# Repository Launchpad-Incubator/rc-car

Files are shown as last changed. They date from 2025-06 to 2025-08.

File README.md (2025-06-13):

# RC Car Control System (Raspberry Pi Pico W + Python)

This project provides a complete system for controlling RC cars over Wi-Fi using Raspberry Pi Pico W microcontrollers. Each car is configured individually, connects to a shared wireless network, and is controlled from a host computer using real-time keyboard input.

## 🚗 Project Components

### 🧠 On the RC Car (Pico W):
- Reads PWM config from `config.json`
- Connects to Wi-Fi using `networkinfo.json`
- Listens for HTTP control commands (`/api?cmd=...&turn=...`)
- Drives an ESC (motor) and servo (steering) using MicroPython

### 💻 On the Control Host (Mac or PC):
- `control_rc_car.py` script
- Sends commands via HTTP using WASD keyboard input
- Uses `.local` mDNS hostnames for multi-car control

---

## 📦 File Structure

```
rc-car-control/
├── main.py               # Pico W control script
├── control_rc_car.py     # Mac/PC keyboard controller
├── config.json           # Pico hardware & hostname config
├── networkinfo.json      # Pico Wi-Fi credentials
├── requirements.txt      # Python dependencies for host control
└── README.md             # You’re here
```

---

## 🛠️ Setup Instructions

### 🔧 1. Flashing the Pico W

1. Flash MicroPython to the Pico W (https://micropython.org/download/rp2-pico-w/)
2. Use [Thonny](https://thonny.org/) to connect to the Pico
3. Upload `main.py`, `config.json`, and `networkinfo.json`
4. Save `main.py` directly on the Pico (not your computer)

### 📡 2. Configuring Wi-Fi and Hostname

Example `config.json` (on the Pico):
```json
{
  "hostname": "rc1",
  "esc_pin": 16,
  "servo_pin": 17
}
```

Example `networkinfo.json` (on the Pico and the computer):
```json
{
  "SSID": "YourWiFiNetwork",
  "PASSWORD": "YourWiFiPassword"
}
```

⌨️ 3. Running the Host Control Script

Install dependencies:
```bash
pip install -r requirements.txt
```

Run the control script:
```bash
python control_rc_car.py
```

You can now control the car using:

    W = Forward
    S = Stop
    A/D = Left/Right steering

---

🚙 Multi-Car Setup

You can run multiple RC cars simultaneously on the same network by:
   1.  Giving each car a unique hostname in its config.json (e.g., rc1, rc2, rc3, …)
   2.  Updating your control script to point to different cars via hostname (rc2.local, etc.)

---

🧪 Testing

    •   Press W while connected to verify motor spin
    •	Watch onboard LED:
    •	Fast blink while connecting to Wi-Fi
    •	Solid once connected
    •	Use ping `rc1.local` to test mDNS resolution

---

📋 Requirements

    •   Raspberry Pi Pico W
    •   GoolRC ESC + Brushless Motor
    •	Servo motor (3-wire)
    •	URGENEX 7.4V 2000mAh battery
    •	Python 3.9+ on control host

---

🤝 Contributing

    1.	Fork the repo
    2.	Create a feature branch (git checkout -b feature/my-feature)
    3.	Commit changes and push
    4.	Open a pull request

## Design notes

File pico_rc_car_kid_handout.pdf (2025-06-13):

## RC Car Code on the Pico W - Explained for Kids

What This Code Does

This code runs on the tiny computer (called a Pico W) that lives inside your RC car. It listens for messages from your laptop over Wi-Fi and makes the car go forward, stop, or turn!

How It Connects to Wi-Fi

At the start of the program, the Pico reads two files:
- config.json: which pins control the motor and the steering
- networkinfo.json: the name and password for your Wi-Fi

It then connects to Wi-Fi. While it's trying to connect, it blinks its little LED light. Once it connects, the light stays on so you know it's ready.

What Is a Class?

In Python, a class is like a blueprint. This code defines a class called RCCar. That blueprint tells the Pico how to control the car: how to drive forward, turn, or stop. We make one real car using that blueprint by writing: car = RCCar(esc, servo).

What is PWM?

PWM stands for Pulse Width Modulation. It means turning power on and off very quickly in pulses. The motor and the steering servo need different length pulses to know what to do. The car sends these using the PWMOutput class.

What is a Socket?

A socket is like a phone line. The Pico sets up a socket and listens on it for incoming messages. When your computer sends a message, the Pico 'picks up the phone' and checks what you said. If you said 'forward', the car moves forward!

How Commands Work

The Pico listens for messages like this:

## RC Car Code on the Pico W - Explained for Kids

GET /api?cmd=forward&turn=left
It looks at the 'cmd' and 'turn' parts and figures out what to do.
- cmd=forward -> drive forward
- turn=left -> steer left
This is called an HTTP GET request. It's how computers ask other computers for something on the web.

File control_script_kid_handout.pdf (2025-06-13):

## RC Car Keyboard Controller - Explained for Kids

What This Program Does

This Python program runs on your computer. It watches your keyboard and sends drive commands to your RC car over Wi-Fi!

How It Knows What Car to Talk To

The program reads config.json to learn the car's hostname, like 'rc1'. It turns that into something like 'http://rc1.local' to send messages to the car.

What is an HTTP Request?

HTTP is a way for computers to ask each other for things, like a website. When you press the 'W' key, your computer sends a message like:
GET /api?cmd=forward&turn=center
The car sees this and goes forward.

How Key Presses Become Car Moves

The program uses a Python package called 'keyboard'. It checks over and over to see which keys are pressed:
- W = go forward
- S = stop
- A = turn left
- D = turn right
Then it sends the right command to the car. If you let go, it tells the car to stop or steer straight.

How Networking Works (Simply)

Think of your home Wi-Fi like a neighborhood. Each device (your computer, the car) has a house number (IP address).
When your computer wants to talk to the car, it sends a letter to that number.
In our case, the letter says something like 'please drive forward'.

## RC Car Keyboard Controller - Explained for Kids

How It Keeps Talking

The program remembers the last command it sent. If nothing has changed, it doesn't send the same command again. This helps it run smoothly without spamming the car.

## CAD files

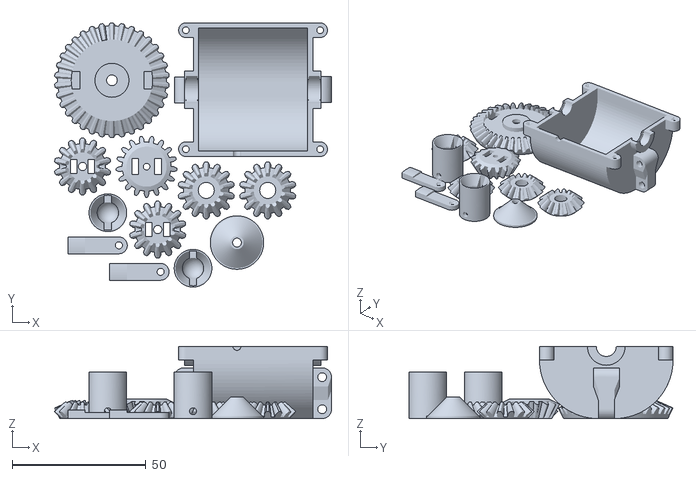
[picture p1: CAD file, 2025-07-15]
RC Car v3.5/Gearbox Batch v1.1.stl
103.6 x 98.8 x 27.0

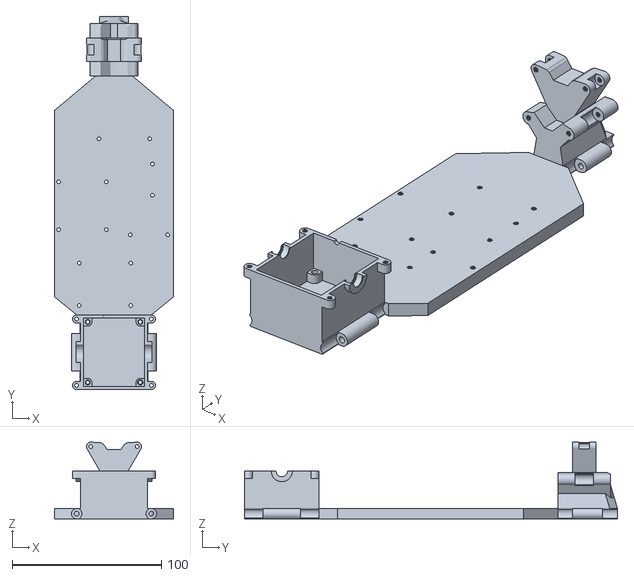
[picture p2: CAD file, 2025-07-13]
RC Car v3.5/PLA/6 Walls, 30% Infill, Tree Support, Crit Regions/RC+car_ parts - Base.stl
80.0 x 250.0 x 51.5

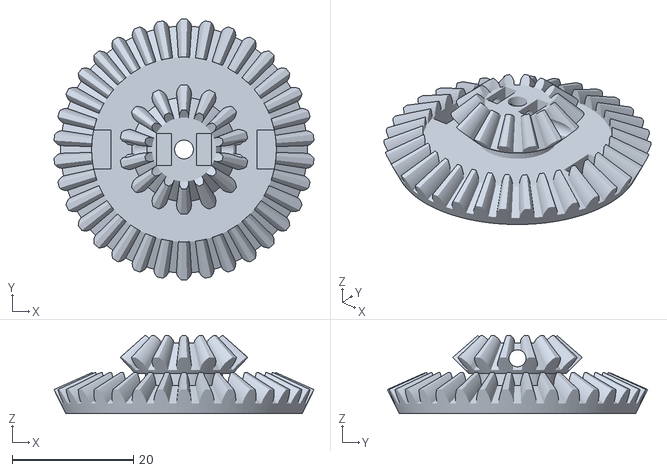
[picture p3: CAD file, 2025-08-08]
RC Car v3.5/PLA/Default/Large+gear_v2.stl
42.9 x 43.0 x 12.9

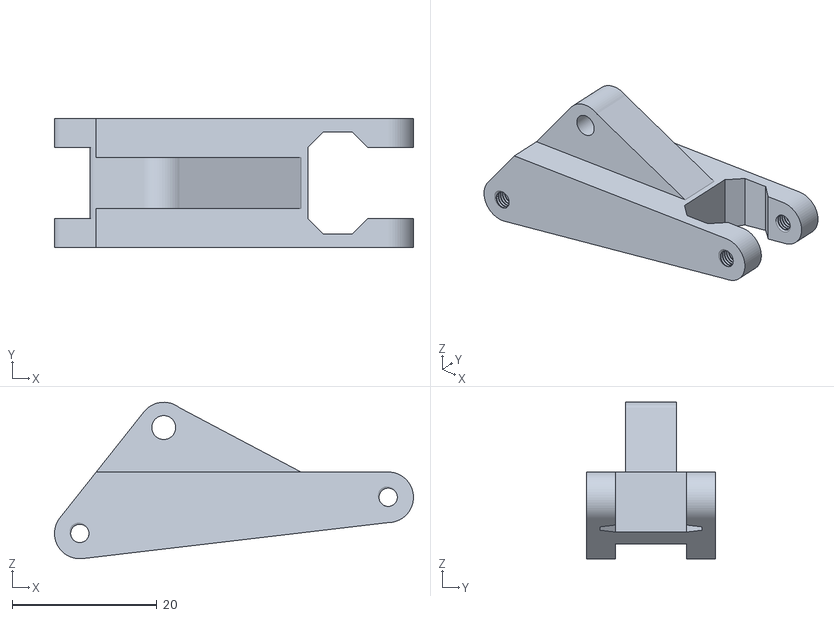
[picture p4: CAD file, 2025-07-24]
RC Car v3.5/PLA/Tree Support, Crit Regions/Back Top Arm v2.stl
49.6 x 17.8 x 21.6

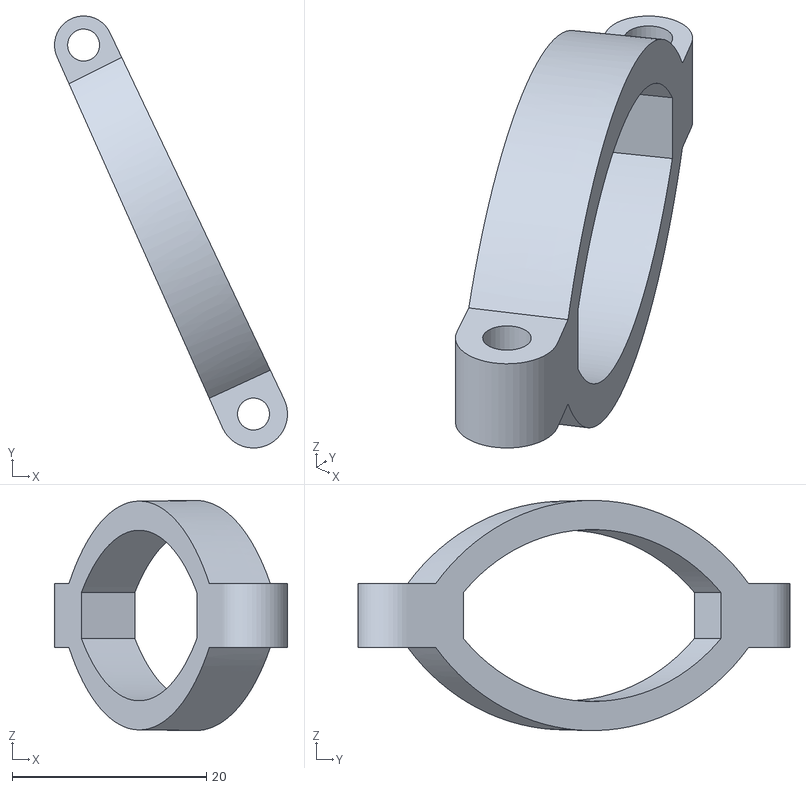
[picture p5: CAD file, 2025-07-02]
RC Car v3.5/TPU/Default/Suspension.stl
24.0 x 44.5 x 23.7

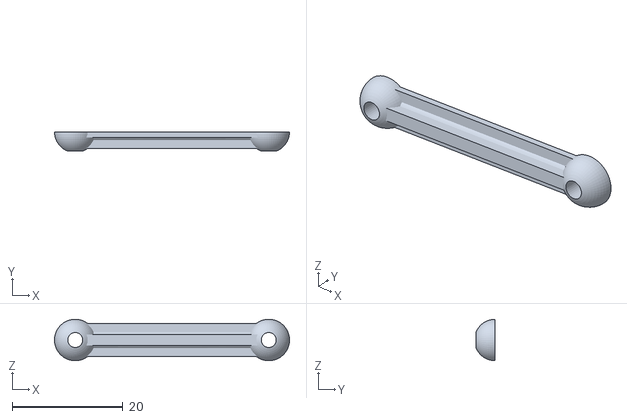
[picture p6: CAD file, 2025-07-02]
RC Car v3.5/PLA/6 Walls, 30% Infill, Tree Support, Crit Regions/Driver+arm.stl
42.5 x 3.50 x 7.49

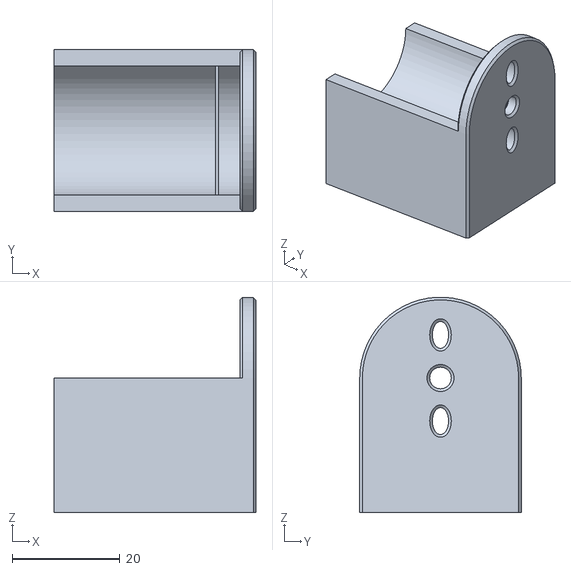
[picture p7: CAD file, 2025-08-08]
RC Car v3.5/PLA/Default/Motor Mount v1.1.stl
37.5 x 30.0 x 40.0

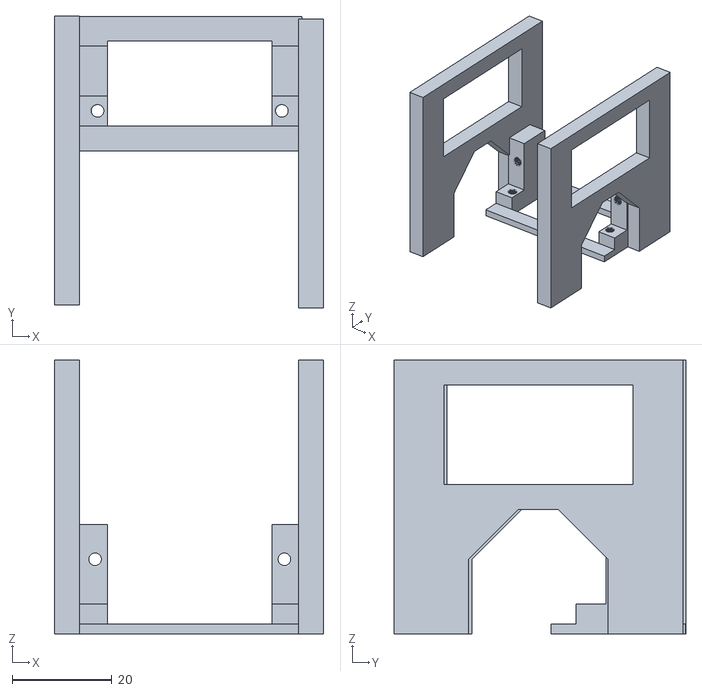
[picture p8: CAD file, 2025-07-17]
RC Car v3.5/PLA/Tree Support, Crit Regions/Servo_Battery_Mount_v2.2.stl
54.0 x 58.6 x 55.0

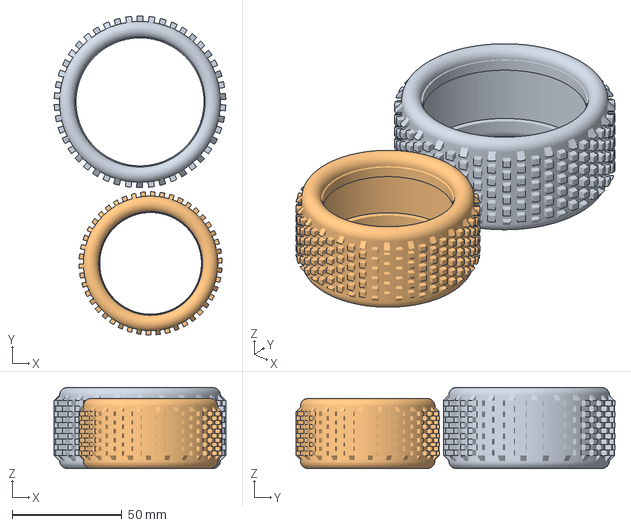
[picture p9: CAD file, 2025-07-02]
RC Car v3.5/TPU/Default/Back+Suspension.3mf
78.4 x 145.6 x 37.0 mm
Rear Tyre v2.stl
Front Tire v2.stl

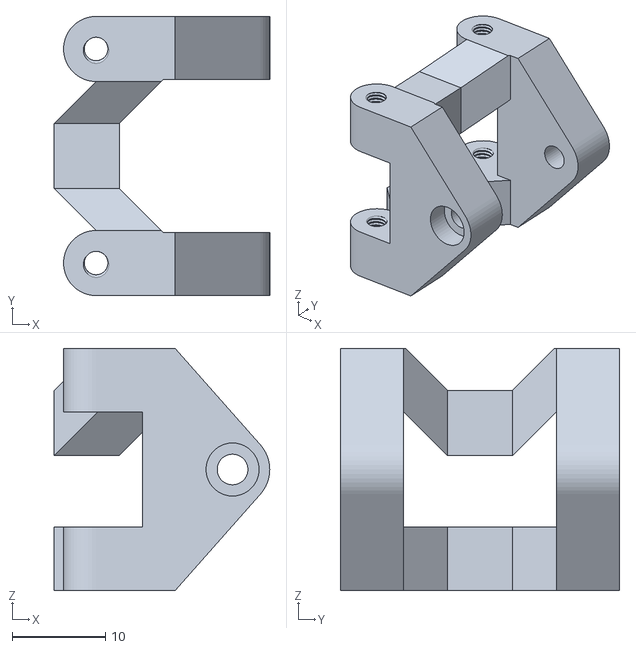
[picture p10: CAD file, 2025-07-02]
RC Car v3.5/PLA/6 Walls, 30% Infill, Tree Support, Crit Regions/Steering+Bracket.stl
23.2 x 30.0 x 26.0

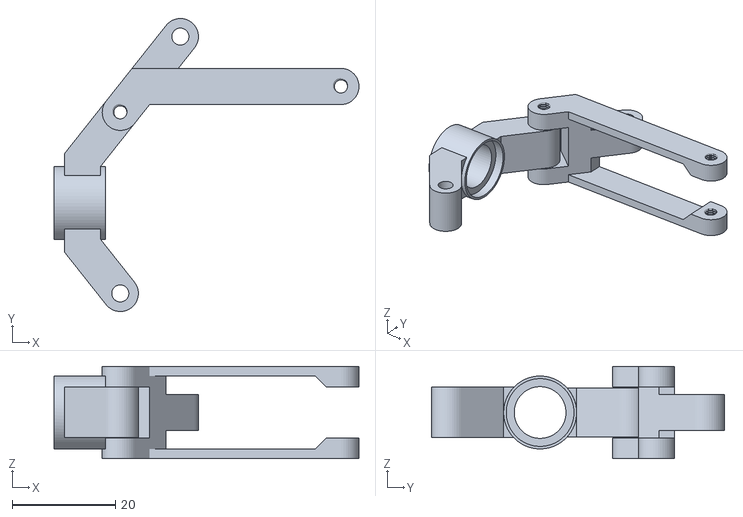
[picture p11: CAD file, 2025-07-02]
RC Car v3.5/PLA/Tree Support, Crit Regions/Back wheel holder.stl
59.0 x 56.6 x 17.8

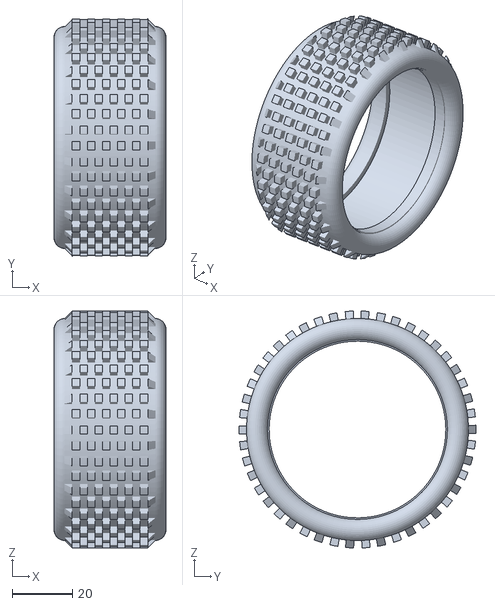
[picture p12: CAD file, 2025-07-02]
RC Car v3.5/TPU/Default/Rear Tyre v2.stl
37.0 x 78.4 x 78.4

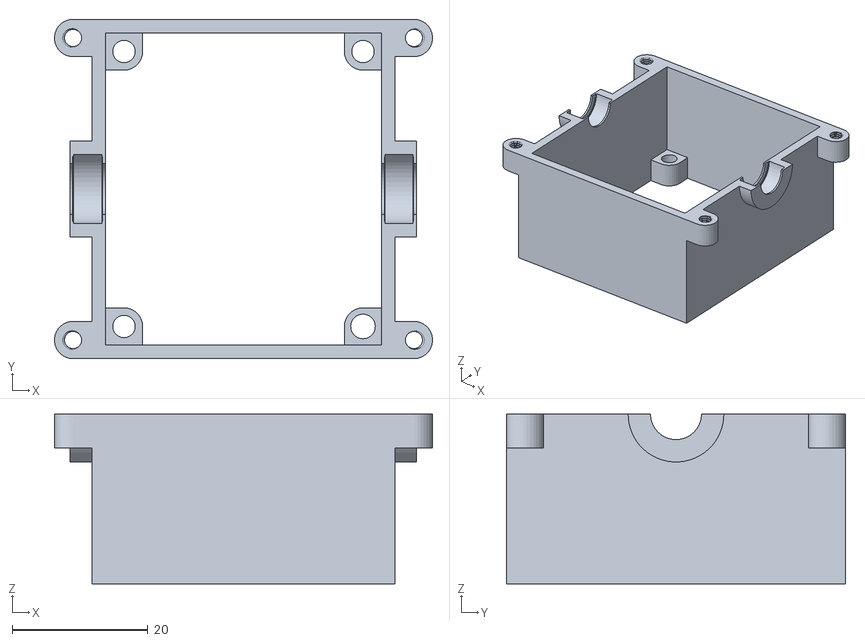
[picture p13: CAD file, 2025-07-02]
RC Car v3.5/PLA/Default/Bottom+Gear+box+UPD.stl
55.7 x 50.0 x 25.0

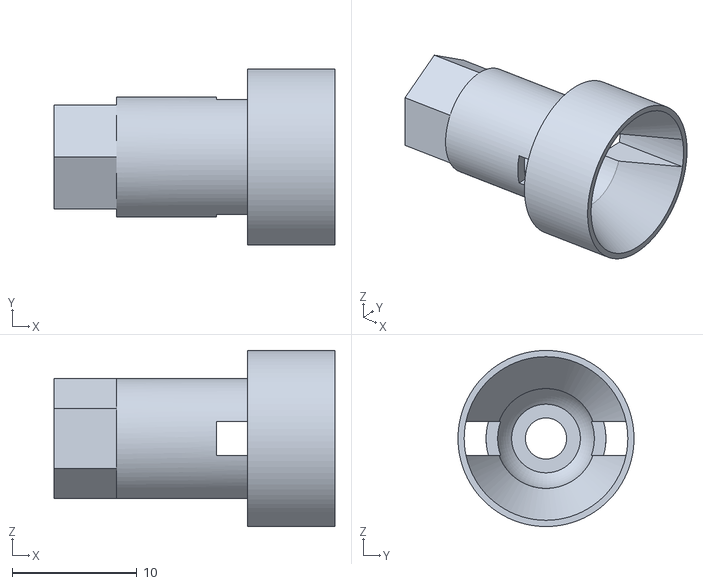
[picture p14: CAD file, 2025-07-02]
RC Car v3.5/PLA/Tree Support, Crit Regions/Back wheel connector.stl
22.5 x 14.1 x 14.1

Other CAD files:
RC Car v3.5/TPU/Default/Front Tire v2.stl
RC Car v3.5/PLA/Default/Inner+gear.stl
RC Car v3.5/PLA/Tree Support, Crit Regions/Back Hub.3mf
RC Car v3.5/PLA/Default/Inner+Driver+Gear.stl
RC Car v3.5/PLA/Default/Back+gearbox+connector.stl
RC Car v3.5/PLA/Default/Driver Gear v3.5.stl
RC Car v3.5/PLA/Default/Fat Washer v1.0.3mf
RC Car v3.5/PLA/Default/Front+arm+top.stl
RC Car v3.5/PLA/Default/Front+arm.stl
RC Car v3.5/PLA/Default/Gear+Arm_v2.stl
RC Car v3.5/PLA/Default/Large+gear.stl
RC Car v3.5/PLA/Default/Rear Wishbone.stl
RC Car v3.5/PLA/Default/Steering+arm.stl
RC Car v3.5/PLA/Default/center+arm.stl
RC Car v3.5/PLA/Tree Support, Crit Regions/Front Hub.stl
RC Car v3.5/PLA/Tree Support, Crit Regions/Top+gear+box.stl
RC Car v3.5/PLA/Tree Support, Crit Regions/Wheel+Bracket.stl
RC Car v3.5/TPU/Default/Back+Suspension.stl

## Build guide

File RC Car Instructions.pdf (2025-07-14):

Supplies

Electronic components:
Motor
Speed controller
Battery
Receiver and transmitter
Servo

Screws:
All the screws are M3 screws unless specified otherwise 4x 8mm
19x 10mm
12x 16mm
8x 22mm
2x 25mm
4x 30mm
4x 40mm
4x nylon locking nut
8x M2.5 5mm set screw
8x M2.5 nut
Other:
3mm Steel Rod (At least 50mm, 25mm each)
9x 623ZZ bearings

Original Instructables File: https://www.instructables.com/3D-Printed-RC-Car/

Step 1: Print Chassis

Send the revised chassis to print.

Step 2: Servo

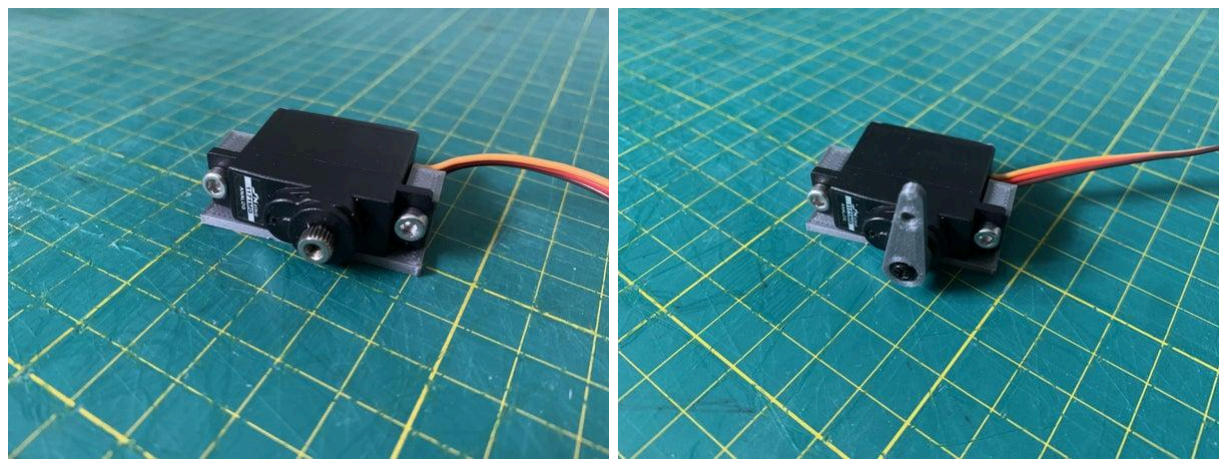
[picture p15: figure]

SKIP IF NOT ATTENDING WEEK 2
Attach the servo to the servo mount using two 10mm screws.
Attach the servo arm to the servo with the really small screw. These parts come with the servo motor.

servo mount.stl (https://content.instructables.com/FE1/2BOT/LJWVJSE4/FE12BOTLJWVJSE4.stl)

servo arm.stl (https://content.instructables.com/F8K/LF18/LJWVJSE5/F8KLF18LJWVJSE5.stl)

Step 3: Steering Arms

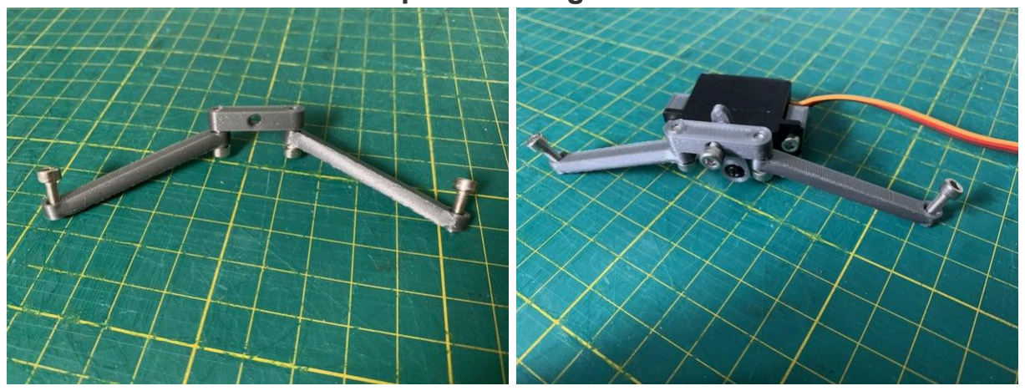
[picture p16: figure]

- Screw the Steering Arms to the Center Arm using 10mm M3 screws. The screws come up from the bottom and the arms “point” downward.
- Make sure that the arms can rotate around the screws freely on both ends of both steering arms. If they do not, loosen the screws slightly. If that doesn’t work, file out the inside of the Steering Arm (not the Center Arm).
- Attach the centre part to the servo arm using the pointy screw that came with the Servo.

Steering arm.stl (https://content.instructables.com/FER/DNH0/LJWVJSEF/FERDNH0LJWVJSEF.stl)

center arm.stl (https://content.instructables.com/FQ3/DND9/LJWVJSEH/FQ3DND9LJWVJSEH.stl)

Step 4: Front Wheels

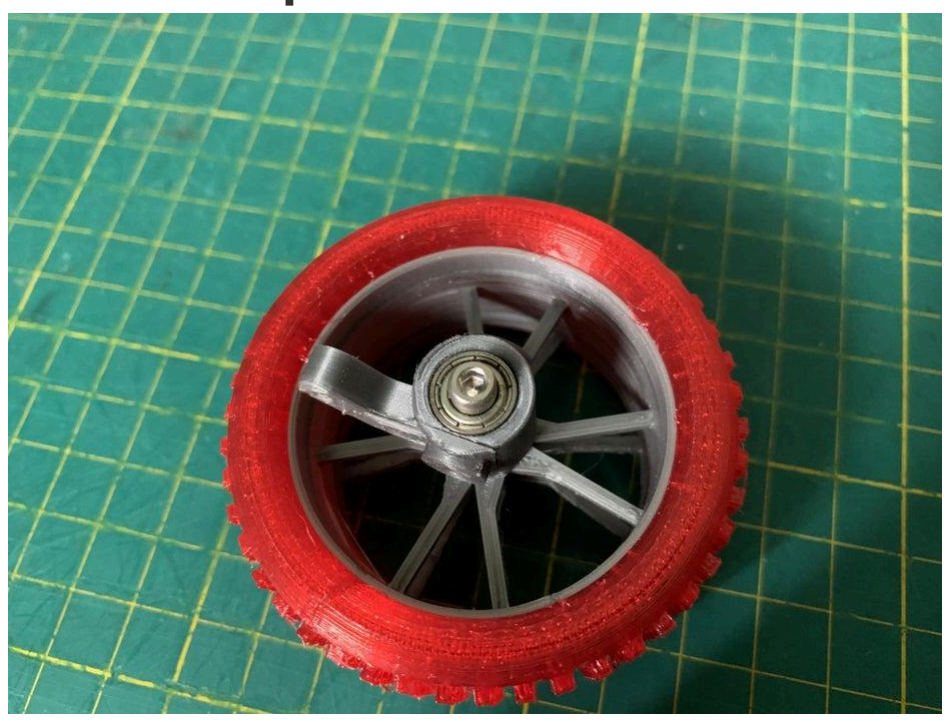
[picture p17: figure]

- Press the bearings into the holes (two on each Wheel Bracket). You will probably need to use a vise.
- Put a 30mm screw through the center of the Wheel Bracket, then a washer, then the Rim.
- Screw on a “Nyloc” nut to stop the Rim from coming off.

Wheel Bracket.stl (https://content.instructables.com/FQH/8DWZ/LJWVJSEU/FQH8DWZLJWVJSEU.stl)

Rim.stl (https://content.instructables.com/F7K/WS2S/LJWVJSEV/F7KWS2SLJWVJSEV.stl)

Tyre.stl (https://content.instructables.com/FEG/O1PX/LJWVJSEW/FEGO1PXLJWVJSEW.stl)

Step 5: Front Arm

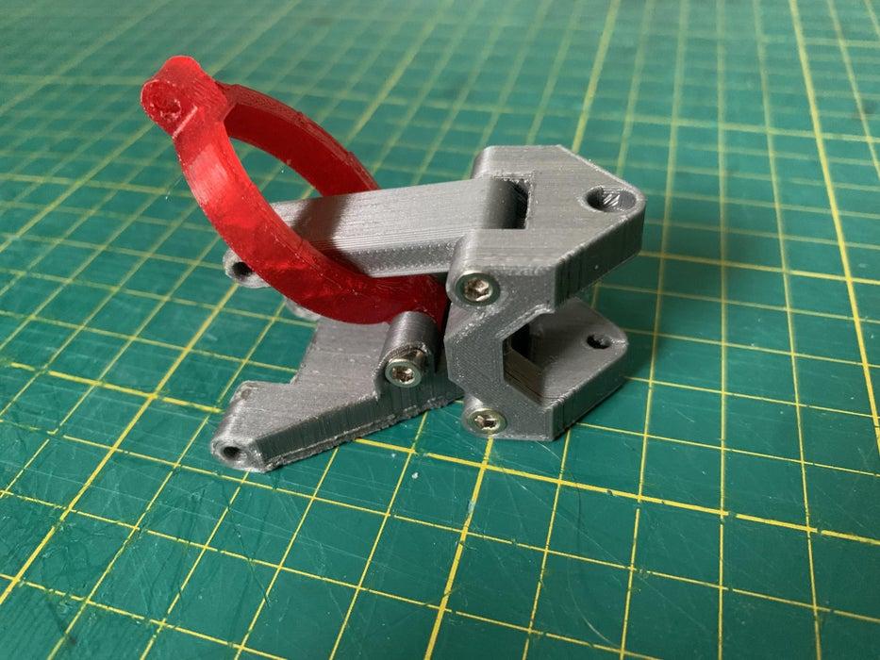
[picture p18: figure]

- Screw the wishbone (front arm) to the chassis using a 40mm screw.
- Screw the wishbone to the steering bracket using 22mm screws.
- Screw the Front Upper Arm to the steering bracket using 22mm screws.
- Screw the suspension piece to the steering bracket (with the thickest piece towards the wheel) using 18mm screws.
- Make sure that all of these pieces can rotate and move freely.
- PRINT 2 (MIRRORED)

Front arm.stl (https://content.instructables.com/F0T/OI95/LJWVJSFE/F0TOI95LJWVJSFE.stl)

Front arm top.stl (https://content.instructables.com/FYB/U8QN/LJWVJSFF/FYBU8QNLJWVJSFF.stl)

Steering Bracket.stl (https://content.instructables.com/FX6/MYU9/LJWVJSFG/FX6MYU9LJWVJSFG.stl)

Suspension.stl (https://content.instructables.com/FYJ/JQRL/LJWVJSFH/FYJJQRLLJWVJSFH.stl)

Step 6: Attaching the Wheel

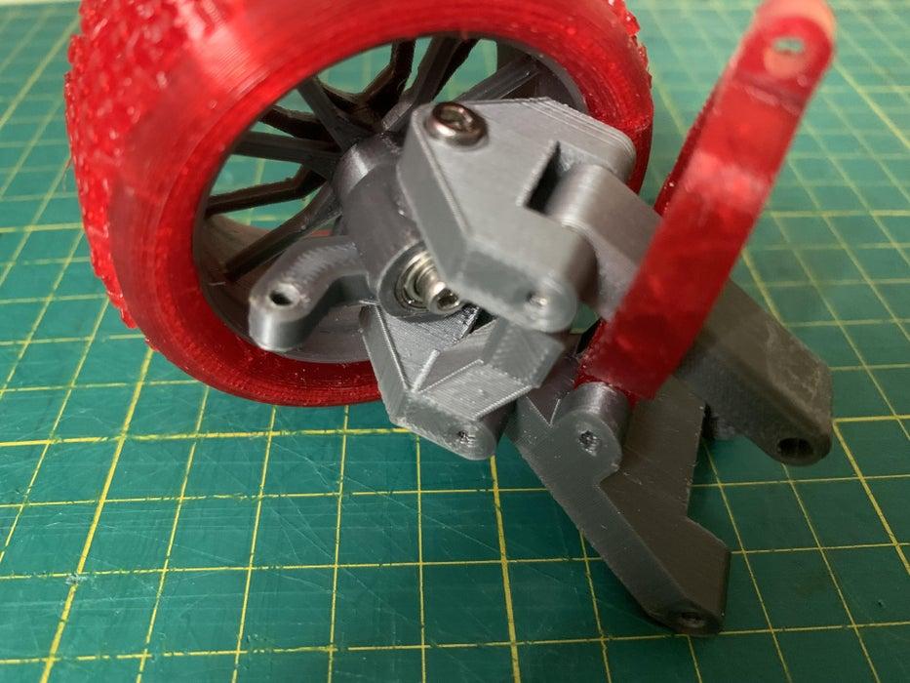
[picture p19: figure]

- Screw Steering Bracket to the Wheel Bracket with 8mm screws for the top and bottom.
- Check that the wheel rotates freely, left to right.
Step 6: Finishing the Front Arms

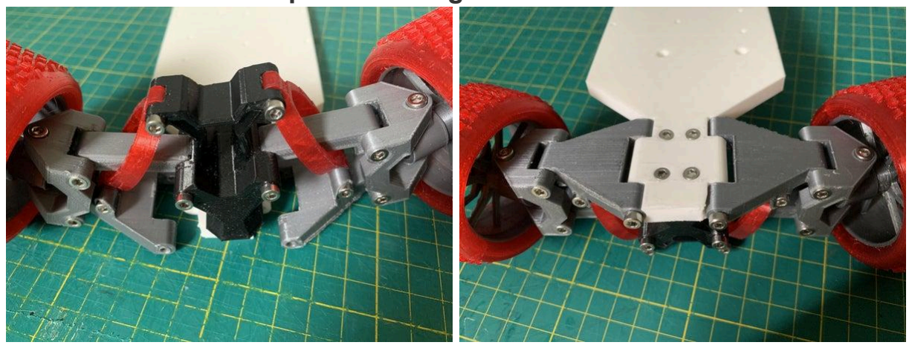
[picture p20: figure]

- Screw the suspension to the Front Arm Bracket (this is now part of the chassis print) using 16mm screws
- Screw on the top wishbones using 30mm screws.

Step 8: Finalising the Steering

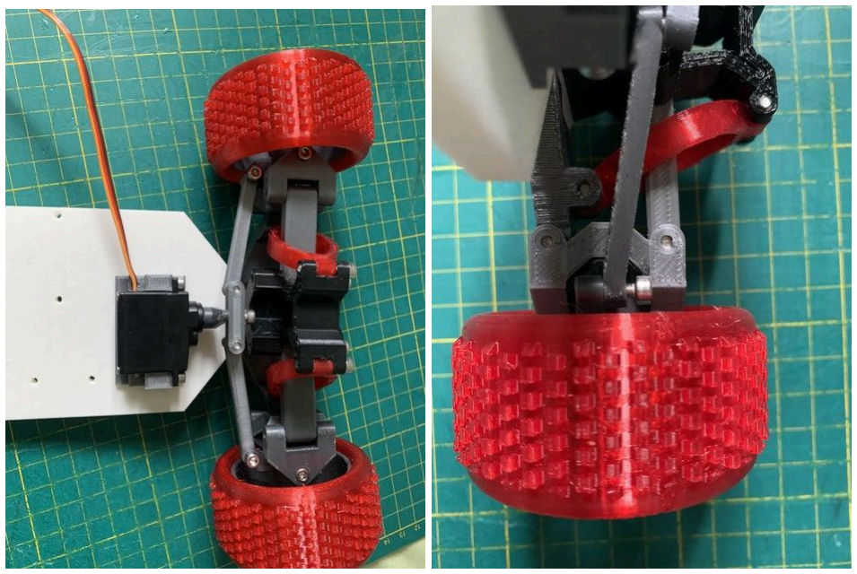
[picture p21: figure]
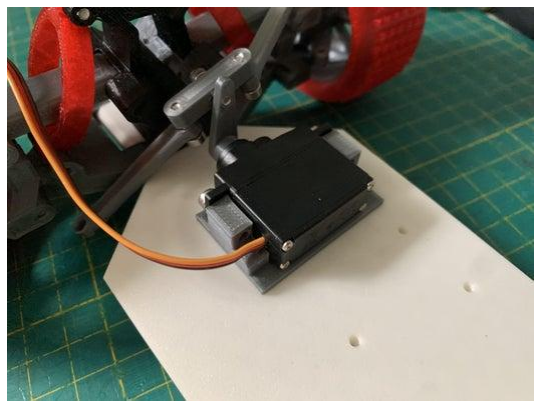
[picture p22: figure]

- Screw the servo to the base using 10mm screws.
- Screw the steering arms to the Wheel Bracket using 10mm screws making sure that there is enough room for the arm to move up and down a little bit.

Step 9: Driver Arm

Print FOUR Driver Arms.

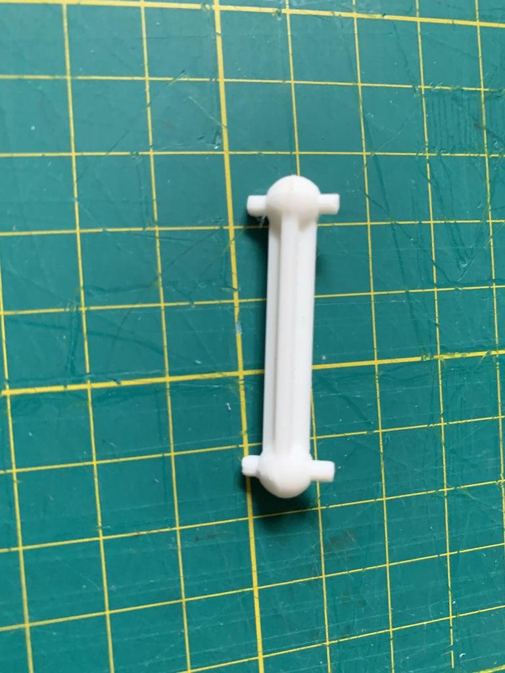
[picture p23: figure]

With those Driver Arms, make TWO identical drive shafts:

- Cut 12 mm long pieces of a 2.5mm aluminum rod, to make each pin (you need 2 pins for each drive shaft, so 4 pins in total).
- Glue the two halves of the drive shafts together with super glue, and use blue tape to hold the pieces in place while the glue dries.
- Once the glue is dry (about 10 minutes), put a small drop of super glue in the hole, and then push the pins through the holes, so they look like the picture above.

Driver arm.stl (https://content.instructables.com/FNH/9UIH/LJWVJSG1/FNH9UIHLJWVJSG1.stl)

Step 10: Small Gear Assembly

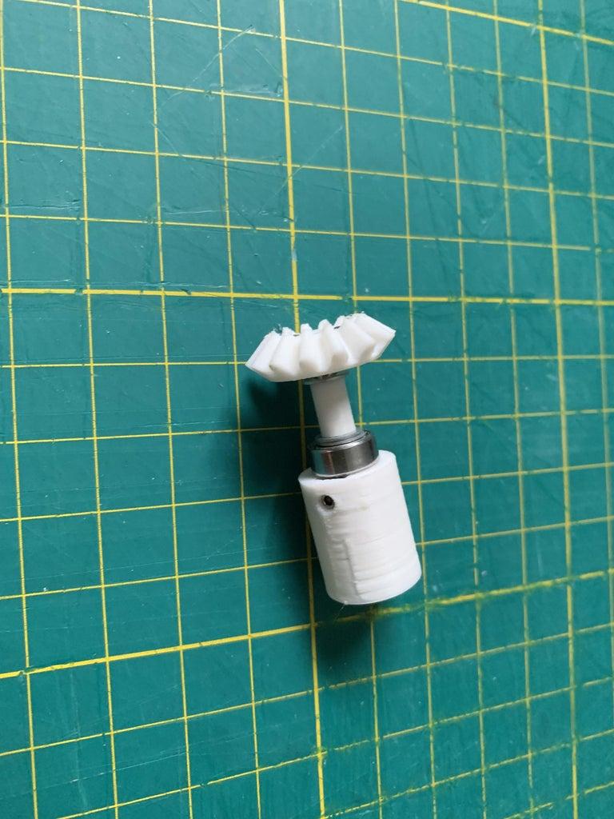
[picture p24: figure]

- Cut a 3mm thick aluminum rod to 23mm (use a hand saw with a “metal” blade). A piece of blue tape at 23mm can act as a guide.
- Put the M2.5 nuts in the slots from the top of the Inner Drive Gear, and screw them in with the M2.5 5mm set screw so the threads just barely catch.
- Insert the gear onto one end of the aluminum rod, and tighten the set screws.
- Put one washer onto the aluminum rod, then the Fat Washer, then two washers, and finally a bearing.
- Check for fit by placing the assembly into the gearbox so that when you put on the gearbox connector, it is not too tight (see the image in Step 10).
- Put the M2.5 nuts in the slots of the gearbox connector, and screw then in with the M2.5 5mm set screws so the threads just barely catch.
- Put the gear box connector onto the aluminum rod, and tighten the set screws.

Inner Driver Gear.stl (https://content.instructables.com/FWM/CVX8/LJWVJSGR/FWMCVX8LJWVJSGR.stl)

Back gearbox connector.stl (https://content.instructables.com/F02/06WU/LJWVJSGT/F0206WULJWVJSGT.stl)

Step 11: Large Gear Assembly

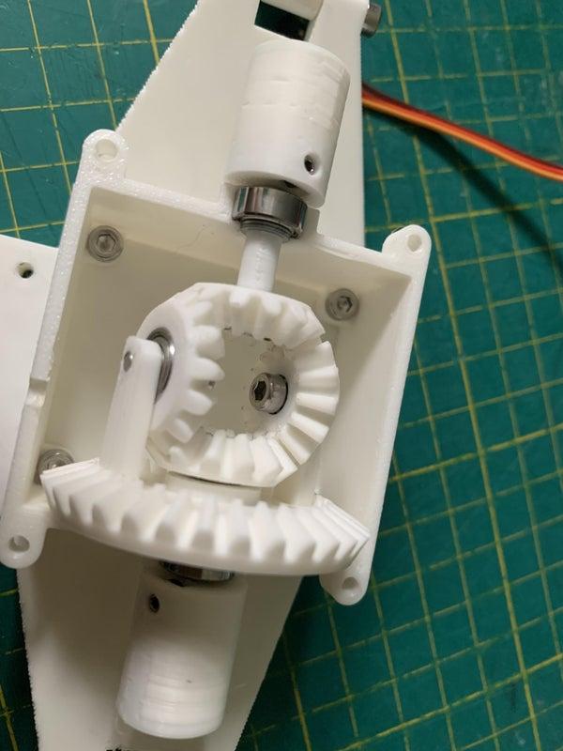
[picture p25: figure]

- Assemble Inner Gear Arm Assemblies
- Put bearings in the Inner Gears (the gears with the hole for the bearing). You may need to use a vise.
- Screw each Inner Gear to a Gear Arm using 8mm screws making sure that they can spin freely.
- Assemble Large Gear Assembly
- Cut a 3mm thick aluminum rod to 45 mm (use a hand saw with a “metal” blade or wire cutters in circles).
- Put in the M2.5 nut in the slots from the top of the Inner Driver Gear, and screw it in with the M2.5 5mm set screw so the threads just barely catch.
- Insert the Inner Drive Gear onto one end of the aluminum rod, and tighten the set screws.
- Press a bearing into the Large Gear, and put it onto the aluminum rod, then another washer
- Assemble the Large Gear Assembly
- Put a drop of super glue into the small rectangular indents on the Large Gear.
- Press the Gear Arms into the Large Gear, making sure that the gears are lined up, and put it aside so that the glue can dry.

Back gearbox connector.stl (https://content.instructables.com/F7Q/WPPE/LJWVJSHJ/F7QWPPELJWVJSHJ.stl)

Small Gear.stl (https://content.instructables.com/FBC/S8TM/LJWVJSHK/FBCS8TMLJWVJSHK.stl)

Gear Arm.stl (https://content.instructables.com/FCL/88L7/LJWVJSHL/FCL88L7LJWVJSHL.stl)

Inner Driver Gear.stl (https://content.instructables.com/F1J/REBV/LJWVJSHM/F1JREBVLJWVJSHM.stl)

Inner gear.stl (https://content.instructables.com/FSI/AYPA/LJWVJSHN/FSIAYPALJWVJSHN.stl)

Large gear.stl (https://content.instructables.com/FPC/1R1D/LJWVJSHO/FPC1R1DLJWVJSHO.stl)

Step 12: Finishing the Gearbox

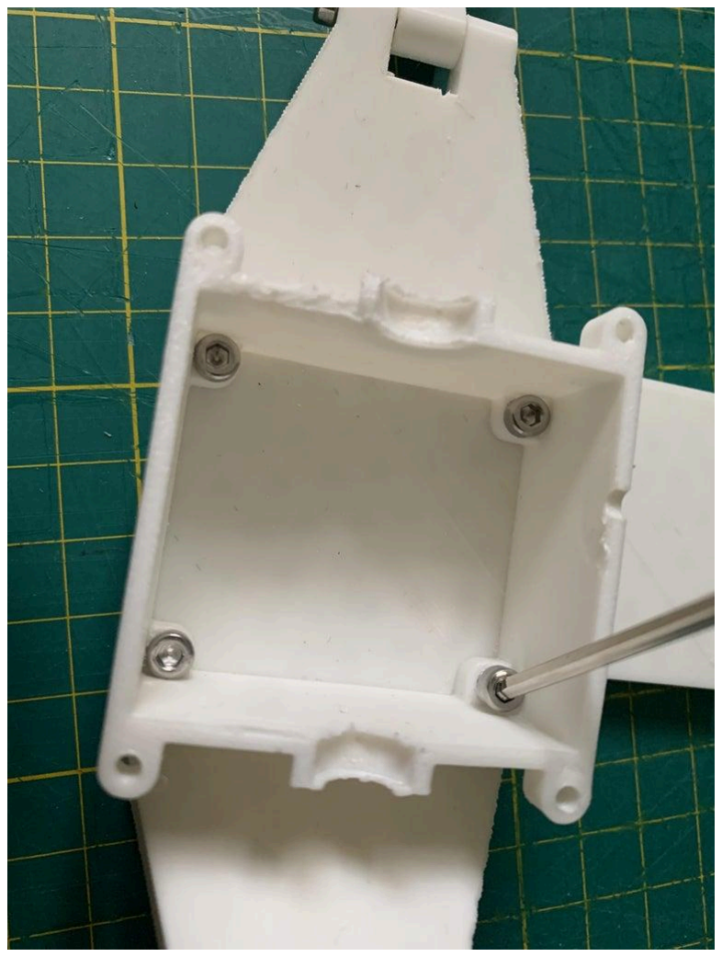
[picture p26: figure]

- Screw the bottom of the gearbox to the Chassis with 10mm screws, and 16mm screws
- Insert all the gears

Bottom Gear box.stl (https://content.instructables.com/F63/7CAI/LJWVJSJD/F637CAILJWVJSJD.stl)

Step 13: Motor

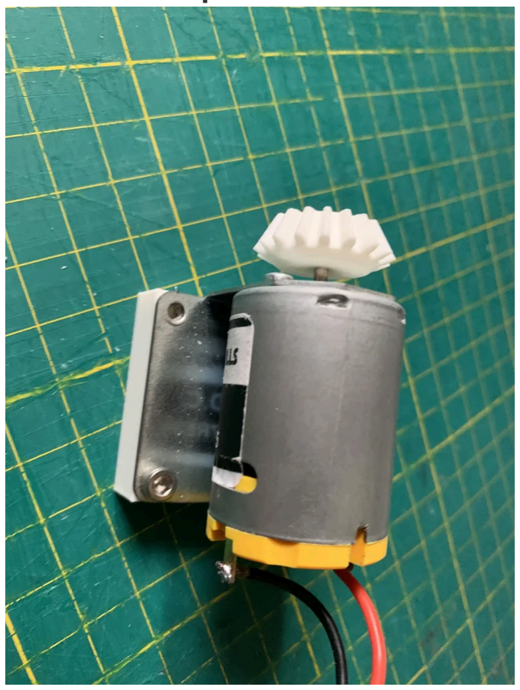
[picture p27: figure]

- Screw the motor onto the Motor Mount (not from the Instructable).
- Screw or glue the motor mount onto the chassis, aligning the drive shaft with the small indent in the gear box. This should be as close to the gearbox as possible.
- Put the M2.5 nuts in the slots from the top of the Motor Gear (not in the Instructable), and screw them in with the M2.5 5mm set screw so the threads just barely catch.
- Insert the gear onto the drive shaft of the motor, and tighten the set screws.

Step 14: Back Arm

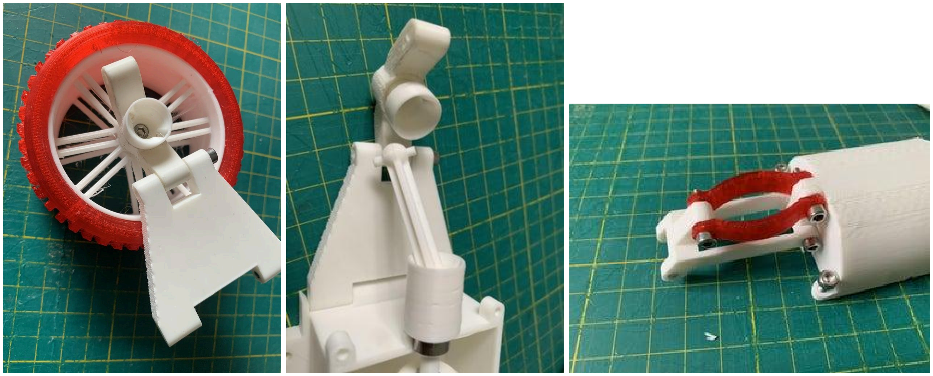
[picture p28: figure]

- Assemble Rear Wheel Assemblies (2 are needed)
- Insert the Back Wheel Connector through the Back Wheel Holder.
- Put an 18mm screw through the Back Wheel Connector.
- Put the Back Wheel Rim onto the screw, and secure them with a NyLock nuts.
- Assemble Upper Suspension Assembly
- Screw the Back Top Arms to the top of the Top Gear using 18mm screws.
- Screw the Back Suspension (there are 4) to the Back Top Arm using 16mm screws.
- Screw the Back Suspension to the Top Gear Box using 16mm screws.
- Screw the Back Wishbone to the chassis using a 40mm screws.
- Screw the Wheel Holder to the bottom wishbone using a 25mm screw.

Back Tyre Hub.stl

Back Suspension.stl (https://content.instructables.com/FHE/1O7Z/LKTZNRNH/FHE1O7ZLKTZNRNH.stl)

Back top arm.stl (https://content.instructables.com/FUI/Q76K/LKTZNRNI/FUIQ76KLKTZNRNI.stl)

Top gear box.stl (https://content.instructables.com/F1Q/ZKMV/LKV65B6J/F1QZKMVLKV65B6J.stl)

Back wheel connector.stl (https://content.instructables.com/FKW/FXJZ/LKWLLFEA/FKWFXJZLKWLLFEA.stl)

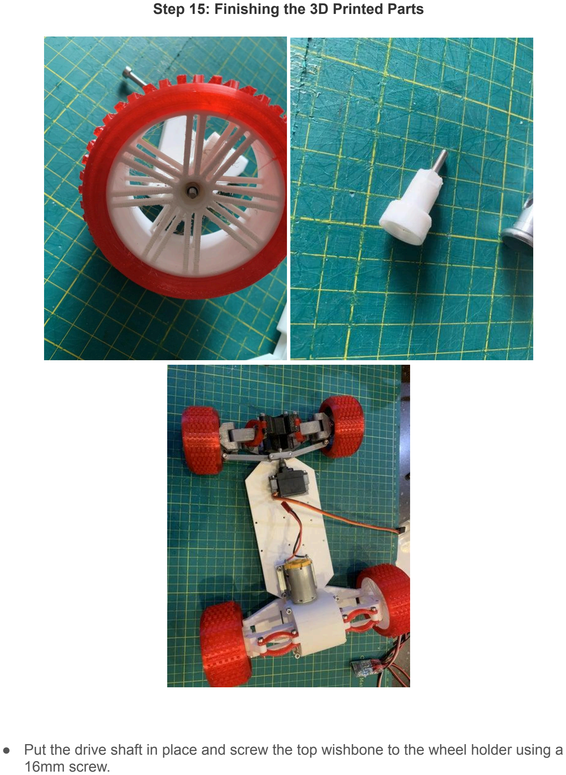
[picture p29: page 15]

Step 15: Finishing the 3D Printed Parts
- Put the drive shaft in place and screw the top wishbone to the wheel holder using a 16mm screw.

## Launchpad’s Tool Glossary

## 🧹 Post-Processing Tools

### 1. Files

- Various grits for smoothing surfaces and ensuring parts fit together seamlessly.

### 2. Flush wire cutter

- For removing supports and cleaning up fine details.

### 3. Sandpaper

- Useful for cleaning up the schmutz leftover from the layers.
- Wet the sandpaper slightly before use.

## ️ Assembly Tools

### 4. Hex Key Set (Allen Wrenches)

- Sizes ranging from 1.5mm to 3mm.
- Use the 2.5mm one.

### 5. Precision Screwdrivers

- Both Phillips and flathead screwdrivers for handling small screws.

### 6. Electric Screwdriver

- To expedite the assembly process, especially when dealing with multiple screws.

### 7. Bench Vise

- For holding parts steady during assembly or when making precise modifications.
- You’ll want this for making sure the bearings are flush into the wheel hub (Step 3).

### 8. Needle-Nose Pliers

- Useful for gripping small parts, bending wires, or holding nuts in tight spaces.

### 9. Wire Cutters and Strippers

- Essential for preparing wires when connecting electronic components.

### 10. Soldering Iron and Accessories

- For connecting wires to motors, batteries, and other electronic components.

### 11. Multimeter

- To test electrical connections and ensure components are functioning correctly.

### 12. Lubricants

- Such as grease or oil, to ensure smooth movement of mechanical parts.

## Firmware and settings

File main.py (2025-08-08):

"""
RC Car Wi-Fi Control Script (Raspberry Pi Pico W)

This script runs on the Pico W to enable wireless control of an RC car using
a web API. It reads configuration for hardware setup and network credentials
from JSON files on the device filesystem. The car can receive movement commands
from a remote client over HTTP and control an ESC (electronic speed controller)
and steering servo via PWM.

Configuration Files:
- config.json: contains hardware pin mappings and hostname
- networkinfo.json: contains Wi-Fi SSID and password

Expected HTTP format:
GET /api?cmd=forward&turn=left

Author: Kevin Thompson
Date: 2025-06-13
"""


import network
import socket
import time
from machine import Pin, PWM
import ujson as json
import _thread



# ==== CONFIGURATION ====

def load_config(config_filename: str) -> dict:
    """Loads a JSON configuration file from the Pico filesystem.
    
    Args:
        config_filename: Name of the file to load.
    
    Returns:
        Parsed dictionary containing config values.
    """
    with open(config_filename) as f:
        return json.load(f)

# Load configurations
cfg = load_config("config.json")
net_cfg = load_config("networkinfo.json")

# Apply configuration values
ESC_PIN: int = cfg.get("esc_pin", 16)
SERVO_PIN: int = cfg.get("servo_pin", 17)

SSID: str = net_cfg.get("SSID", "")
PASSWORD: str = net_cfg.get("PASSWORD", "")

# Onboard LED setup
LED = Pin("LED", Pin.OUT)

# ==== PWM Helpers ====
class PWMOutput:
    """Handles PWM signal output for servos or ESCs."""
    def __init__(self, pin_num: int) -> None:
        self.pwm = PWM(Pin(pin_num))
        self.pwm.freq(50)  # Standard RC frequency
    
    def set_pulse(self, microseconds: int) -> None:
        """Sets a PWM duty cycle based on a pulse width.
        
        Args:
            microseconds: Duration of the high pulse in microseconds (1000-2000 typical).
        """
        duty = int(microseconds / 20000 * 65535)
        self.pwm.duty_u16(duty)

# ==== RC Controller ====
class RCCar:
    """Represents a remotely controlled RC car with drive and steering PWM outputs."""
    def __init__(self, esc, servo):
        self.esc = esc
        self.servo = servo
        # Calibration Must Come before other signals to initialize the ESC
        self.init_ESC()
        self.stop()
        self.center()
    
    def forward(self) -> None:
        self.esc.set_pulse(1490)
    
    def stop(self) -> None:
        self.esc.set_pulse(1460)
    
    def left(self) -> None:
        self.servo.set_pulse(1200)
    
    def right(self) -> None:
        self.servo.set_pulse(1800)
    
    def center(self) -> None:
        self.servo.set_pulse(1500)
        
    def back(self) -> None:
        self.esc.set_pulse(1440)

    def init_ESC(self) -> None:
        self.esc.set_pulse(1000)
        time.sleep(1)

# ==== Connect to Wi-Fi ====
def connect_wifi(ssid: str, password: str):
    """Connects to a Wi-Fi network.
    
    Args:
        ssid: Wi-Fi SSID
        password: Wi-Fi password
    
    Returns:
        IP address as a string
    """
    
    ip = wlan.ifconfig()[0]
    
    while wlan.status() != 3: # 3 is the status for AP being active
        LED.toggle()
        time.sleep(0.25)
    
    LED.on()
    print(f"Access Point created. IP address: {ip}")
    return ip


# ==== Handle Requests ====
def handle_api_request(request: str, car: RCCar) -> None:
    """Parses an incoming API request and updates car state.

    Args:
        request: Raw HTTP GET request string
        car: RCCar instance to control
    """
    try:
        query = request.split('GET /api?')[1].split(' ')[0]
        print(f"Incoming request: {query}")
        params = query.split('&')
        for p in params:
            if p.startswith('cmd='):
                cmd = p[4:]
                if cmd == 'forward':
                    car.forward()
                elif cmd == 'stop':
                    car.stop()
                elif cmd == 'back':
                    car.back()
                print(f"Drive Command: {cmd}")
            elif p.startswith('turn='):
                direction = p[5:]
                if direction == 'left':
                    car.left()
                    print("turn left")
                elif direction == 'right':
                    car.right()
                    print("turn right")
                elif direction == 'center':
                    car.center()
                    print("centering")
                print(f"Steering Command: {direction}")
    except Exception as e:
        print("Error parsing request:", e)


# ==== Main Entry ====
def main() -> None:
    """Main entry point: sets up car, connects Wi-Fi, and starts HTTP server."""
    print("main() started")
    print("Calling connect_wifi()...")
    ip, wlan = connect_wifi(SSID, PASSWORD)
    print("Back from connect_wifi(), starting server...")

    esc = PWMOutput(ESC_PIN)
    servo = PWMOutput(SERVO_PIN)
    car = RCCar(esc, servo) # delays for 1 second for calibration
    
    addr = socket.getaddrinfo('0.0.0.0', 80)[0][-1]
    sock = socket.socket()
    sock.setsockopt(socket.SOL_SOCKET, socket.SO_REUSEADDR, 1)
    sock.bind(addr)
    sock.listen(1)
    
    print(f"Server listening on http://{ip}/api?cmd=...")
    
    while True:
        cl, addr = sock.accept()
        try:
            request = cl.recv(1024).decode()
            print("Request received:")
            print(request)
            if 'GET /api?' in request:
                handle_api_request(request, car)
                cl.send("HTTP/1.1 204 No Content\r\n\r\n")
            else:
                cl.send("HTTP/1.1 404 Not Found\r\n\r\n")
        except Exception as e:
            print("Request error:", e)
        finally:
            cl.close()

main()

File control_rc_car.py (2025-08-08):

"""
RC Car Keyboard Controller (Desktop Python)

This script runs on your local computer and listens for
WASD keyboard input to control a Raspberry Pi Pico W–powered RC car over Wi-Fi.

Each key press sends an HTTP GET request to the car's API, using the car's
hostname defined in a local `config.json` file.

Keys:
    W → Forward
    A → Turn left
    D → Turn right
    S → Stop (and center steering)

Configuration File:
- config.json: contains "hostname" for the target RC car

Authors: Kevin Thompson, Aidan McMillan
Date: 2025-07-23
"""

import keyboard
import requests
import time
import json
import socket
from typing import Optional

def load_config() -> dict:
    """Loads the control configuration from a local JSON file.
    
    Returns:
        Dictionary containing config values (e.g., hostname).
    """
    with open("config.json") as f:
        return json.load(f)

cfg = load_config()
SSID: str = cfg.get("SSID")
PICO_IP: str = "192.168.4.1"
DEBOUNCE_MS: int = 50

print(socket.gethostbyname(PICO_IP))

def send_command(command: str) -> None:
    """Sends a command to the RC car's API endpoint over HTTP.
    
    Args:
        command: Query string in the format "cmd=forward&turn=left"
    """
    url = f"http://{PICO_IP}/api?{command}"
    try:
        response = requests.get(url, timeout=10)
        print(f"Sent: {command} | Status: {response.status_code}")
    except Exception as e:
        print(f"Failed to send: {command} | Error: {e}")

def main() -> None:
    """Main control loop: monitors keyboard and sends commands to the Pico W."""
    last_command = None

    print("Keyboard RC Control Started")
    print("Hold W = forward, A/D = steer, S = back")

    while True:
        drive_command = 'stop'
        turn_command = 'center'

        if keyboard.is_pressed('w'):
            drive_command = "forward"
        elif keyboard.is_pressed('s'):
            drive_command = "back"
        
        if keyboard.is_pressed('a'):
            turn_command = "left"
        elif keyboard.is_pressed('d'):
            turn_command = "right"
        
        full_command = f"cmd={drive_command}&turn={turn_command}"

        if full_command != last_command:
            send_command(full_command)
            last_command = full_command
        
        time.sleep(DEBOUNCE_MS / 1000)

if __name__ == "__main__":
    main()

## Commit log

2025-06-13 added kid-friendly handouts for the control script and the pico rc car script
2025-06-13 main needs serious fixing, but control_rc will actually work now
    [control_rc_car.py, main.py]
2025-07-13 Update Base
    [RC+car_ parts - Base.stl]
2025-07-23 no longer need to pass hostname to connect_wifi
    [main.py]
2025-07-30 Added back() to RCCar and added a calibration to get ESC started
2025-07-30 Fixed ESC initialization protocol, added test ESC code as well that eliminates Wifi and command parsing
2025-08-05 Update control_rc_car.py to make Aidan's code easier to use
    Doesn't hurt users of this code.
    [control_rc_car.py]
2025-08-06 Added Large Gear v2 and updated code
    [Large+gear_v2.stl]
2025-08-07 Update Motor Mount
    [Motor Mount v1.0.stl, Motor Mount v1.1.stl]
2025-08-07 Create Chassis6.4.25 (3).stl_PLA_5h27m17s.gcode
2025-08-07 Rename Chassis6.4.25 (3).stl_PLA_5h27m17s.gcode to Chassis.gcode
